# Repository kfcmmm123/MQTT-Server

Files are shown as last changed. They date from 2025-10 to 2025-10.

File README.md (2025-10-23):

# ESP32-POE-ISO IoT Control System
**Modular MQTT-Based Automation for Pumps, Ultrasonic Drivers, and Heaters**

This repository hosts a **multi-device IoT control platform** built on **ESP32-POE-ISO** boards communicating via **MQTT over Ethernet**.  
Each ESP32 node acts as a standalone controller for a subsystem (Pump, Ultrasonic, or Heater), while a Python controller (`iot_mqtt.py`) provides orchestration, supervision, and visualization.

---

## Project Overview

| Component | Description |
|---|---|
| **ESP32-POE-ISO Nodes** | Independent nodes for each subsystem. Each node runs its own safety-supervised firmware. |
| **Python Controller** | Publishes heartbeat and commands; logs telemetry from all devices. |
| **Mosquitto Broker** | Central MQTT message hub managing device topics and access control. |
| **CAD Models** | Modular enclosures for each ESP node and relay system. |

Each subsystem connects through a unified topic schema and supports **autonomous safety shutdown**, **timed operation**, and **real-time telemetry**.

---

## Features

- **Modular MQTT Architecture:** each node operates independently but shares a common protocol.
- **Ethernet + PoE Isolation:** hardware-level safety and simplified wiring.
- **PID Temperature Control:** with ADS1015 ADC + NTC thermistors for precise heater regulation.
- **Relay Control (I²C/Qwiic):** reliable actuation of pumps, heaters, and ultrasonic drivers.
- **Safety Supervision:** heartbeat monitoring, link detection, MQTT reconnection handling, and auto-failsafe.
- **Cross-Platform Python API:** unified control, MQTT utilities, and broker automation.

---

## Repository Structure

```
MQTT-Server/
│
├── README.md                     # Project overview & quickstart
│
├── devices/                      # ESP32 firmware & documentation
│   ├── pump/                        # Pump control firmware
│   │   ├── Pump_quad_client.ino     # Quad relay pump controller
│   │   ├── Pump_single_client.ino   # Single relay pump controller  
│   │   ├── Pump_Safety_client.ino   # Safety-enabled version for single relay
│   │   └── README.md                # Pump setup guide
│   │
│   ├── ultrasonic/                  # Ultrasonic driver control
│   │   ├── Ultrasonic_quad_client.ino          # Quad relay ultrasonic controller
│   │   ├── Ultrasonic_single_client.ino        # Single relay ultrasonic controller
│   │   ├── Ultrasonic_Safety_client.ino        # Safety-enabled version for single relay
│   │   └── README.md                # Ultrasonic setup guide
│   │
│   └── heater/                      # Heater control with PID
│       ├── Heater_client.ino        # Main heater firmware
│       ├── Heater_Safety_client.ino # Safety-enabled version
│       └── README.md                # Heater setup guide
│
├── iot_mqtt/                     # Python control library
│   ├── iot_mqtt.py                  # Unified MQTT API
│   ├── MQTT_Demo.ipynb              # Example Jupyter notebook
│   └── README.md                    # Python API documentation
│
├── mosquitto_config/             # MQTT broker configuration
│   ├── mosquitto.conf               # Broker settings
│   ├── aclfile.txt                  # Access control list
│   └── README.md                    # Broker setup guide
│
└── hardware/                     # 3D printable enclosures
    ├── CAD_models/                  # 3MF files for printing
    └── README.md                    # Hardware assembly guide
```

---

## System Architecture

```text
                 ┌─────────────────────────────┐
                 │         MQTT Broker         │
                 │        (Mosquitto)          │
                 │       Port 1883 (TCP)       │
                 └──────────────┬──────────────┘
                                │
                         Ethernet TCP/IP
          ┌─────────────────────┼────────────────────┐
          │                     │                    │                    
┌─────────┴──────────┐  ┌───────┴────────┐   ┌───────┴─────────┐
│ ESP32-POE-ISO      │  │ ESP32-POE-ISO  │   │ ESP32-POE-ISO   │
│ Node: pumps/01     │  │ Node: ultra/01 │   │ Node: heat/01   │
│ Relays (pumps)     │  │ Relays (ultra) │   │ SSR + ADS1015   │
└────────────────────┘  └────────────────┘   └─────────────────┘

````

---

## Device Overview

| Node | Features | Firmware |
| --- | --- | --- |
| **Pump Node** | Controls up to 4 DC peristaltic pumps via Qwiic relay | `devices/pump/Pump_Safety_client.ino`|
| **Ultrasonic Node** | Controls 2 ultrasonic driver boards via Qwiic relay | `devices/ultrasonic/Ultrasonic_Safety_client.ino` |
| **Heater Node** | Controls 2 heaters via Qwiic SSR + thermistor sensing + PID + safety brake | `devices/heater/Heater_Safety_client.ino` |

Each firmware implements MQTT topic handlers, safety gating, and local timers for timed activation (`ON:<ms>`).

---

## Software Stack

| Layer | Technology |
| --- | --- |
| **Hardware** | ESP32-POE-ISO (Olimex) |
| **Firmware** | Arduino framework |
| **Communication** | MQTT (paho-mqtt / PubSubClient) |
| **Broker** | Mosquitto |
| **Python API** | `iot_mqtt.py` |
| **Safety** | Heartbeat + LWT watchdogs |

---

## Security and Safety Summary

* **MQTT ACLs:** device-level topic restrictions in `mosquitto_config/aclfile.txt`
* **LWT Fail-safe:** controller disconnect triggers `OFFLINE` → all nodes shut down
* **Timeouts:** configurable per-device heartbeat timeouts
* **Hardware:** PoE isolation + fused 12 V supply + SSR isolation
* **Emergency Stop:** physical NC E-stop in series with actuator supply

---

## Quick Start

### Prerequisites
- ESP32-POE-ISO boards (Olimex)
- SparkFun Qwiic relay modules
- Python 3.8+ with `paho-mqtt` library
- Arduino IDE with ESP32 support

### 1. Setup MQTT Broker
```bash
# Install Mosquitto (Windows)
choco install mosquitto

# Or Linux
sudo apt install mosquitto mosquitto-clients

# Configure broker (see mosquitto_config/README.md)
mosquitto -v -c mosquitto_config/mosquitto.conf
```

### 2. Flash ESP32 Devices
1. Open Arduino IDE
2. Install ESP32 board support
3. Flash firmware from `devices/` folders:
    - **Pump Node**: `devices/pump/Pump_Safety_client.ino`
    - **Ultrasonic Node**: `devices/ultrasonic/Ultrasonic_Safety_client.ino`
    - **Heater Node**: `devices/heater/Heater_Safety_client.ino` 

### 3. Run Python Controller
```bash
# Install dependencies
pip install paho-mqtt

# Run example
python iot_mqtt/iot_mqtt.py
```

### 4. Monitor System
```bash
# Watch all MQTT traffic
mosquitto_sub -v -t "#" -u pyctl-controller -P controller
```

### 5. Test Devices
```python
import time
from iot_mqtt import PumpMQTT, UltraMQTT, HeatMQTT

# Control pumps
pumps = PumpMQTT(broker="192.168.0.100", username="pump1", password="pump")
pumps.ensure_connected()
pumps.on(1, 2000)  # Pump 1 for 2 seconds

# Control ultrasonic drivers
ultra = UltraMQTT(broker="192.168.0.100", username="ultra1", password="ultra")
ultra.ensure_connected()
ultra.on(1, 2000)  # Ultrasonic 1 for 2 seconds

# Control heaters with PID
heat = HeatMQTT(broker="192.168.0.100", username="heat1", password="heat")
heat.ensure_connected()
heat.set_target(1, 42.0)  # Set 42°C target
heat.pid_on(1)            # Enable PID control
time.sleep(2)             # On for 2 seconds
heat.set_target(1, 42.0)  # Set 42°C target
heat.pid_on(1)            # Enable PID control
```

---

## Documentation & Guides

### Setup & Configuration
- **[MQTT Broker Setup](./mosquitto_config/README.md)** - Mosquitto installation, users, ACL configuration
- **[Python API Guide](./iot_mqtt/README.md)** - Complete Python library documentation with examples
- **[Hardware Assembly](./hardware/README.md)** - 3D printable enclosures and assembly instructions

### Device-Specific Guides  
- **[Pump Controllers](./devices/pump/README.md)** - 4-pump relay control setup and wiring
- **[Ultrasonic Controllers](./devices/ultrasonic/README.md)** - AC driver control via relays
- **[Heater Controllers](./devices/heater/README.md)** - Dual SSR + PID temperature control

### Development Resources
- **[Jupyter Demo](./iot_mqtt/MQTT_Demo.ipynb)** - Interactive examples and testing
- **[CAD Models](./hardware/CAD_models/)** - 3MF files for 3D printing enclosures
- **[BOM](./hardware/BOM/)** - Bill of Materials for the setup

---

## Troubleshooting

### Common Issues

**ESP32 won't connect to MQTT**
- Check broker IP address in firmware (use `ipconfig` to verify network settings)
- Verify Ethernet connection and PoE power supply
- Confirm MQTT credentials match ACL configuration

**Broker stops responding with continuous client reconnections**
> **IMPORTANT**: This indicates a critical broker failure!
- Stop the broker immediately and wait until `netstat -ano | findstr :1883` shows no output
- Restart Jupyter/kernel to clear client connections
- **Root cause**: Server failure causes clients to reconnect with same client IDs, creating connection conflicts that overwhelm the broker

**Broker startup fails**
- Check for existing broker process: `netstat -ano | findstr :1883`
- If process exists, kill it: `taskkill /IM mosquitto.exe /F`
- Verify broker configuration: `ipconfig`, and port availability (default 1883)

**Devices show OFFLINE**
- Verify controller beacon is running (`pyctl/heartbeat` topic)
- Check heartbeat intervals (default 15s)
- Ensure LWT (Last Will & Testament) is properly configured

**Python API connection fails**
- Install required dependencies: `pip install paho-mqtt`
- Check broker address and port (default 1883)
- Verify user credentials match broker configuration (also check for user access rights in ACL file)
- **Check Python controller log file** - The `iot_mqtt.py` has built-in logging that writes detailed connection and communication logs to a log file

**Python controller issues**
- Check the log file created by `iot_mqtt.py` for detailed error messages and connection status
- Log file contains MQTT connection attempts, device status updates, and communication errors
- Look for authentication failures, connection timeouts, or topic permission errors in the logs

### Getting Help

**Debug MQTT Communication**
```bash
# Monitor all MQTT traffic
mosquitto_sub -v -t "#" -u pyctl-controller -P controller

# Check specific device topics
mosquitto_sub -v -t "pumps/01/#" -u pump1 -P pump
mosquitto_sub -v -t "heat/01/#" -u heat1 -P heat
```

**Additional Resources**
- **Check Python controller log file** - Built-in logging provides detailed connection status, MQTT communication, and error messages
- Check device-specific README files for detailed troubleshooting
- Review broker logs for authentication and connection issues
- Verify network connectivity with `ping <broker-ip>`
- Test broker connectivity: `mosquitto_pub -h <broker-ip> -t "test" -m "hello"`

---

## License

**MIT License**

© 2025 Alan Yang — Acceleration Consortium, University of Toronto

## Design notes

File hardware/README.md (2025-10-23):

# Hardware Assembly — Modular Tower System

This folder contains the **3D-printable designs** and assembly instructions for the modular tower system, including the Power Tower base unit, interchangeable module plates, and accessories for the IoT control system.

## Quick Links

- **[Python API Documentation](../iot_mqtt/README.md)** - Control ESP32 devices via Python
- **[Device Firmware](../devices/)** - ESP32 firmware for pumps, heaters, ultrasonic controllers
- **[MQTT Broker Setup](../mosquitto_config/README.md)** - Mosquitto configuration and security

---

## CAD Files

```
hardware/
├── CAD_models/                 # 3D printable enclosure files
│   ├── Base Power Tower.3mf
│   ├── Heater Module - SSR.3mf
│   ├── Pump Module - 3 single relay.3mf
│   ├── Pump Module - quad relay.3mf
│   ├── Ultrasonic Driver Module.3mf
│   └── Ultrasonic Module - 2 single relay.3mf
│
├── BOM/                        # Bill of Materials 
│   └── Modular MQTT Tower.xlsx 
│
├── Images/                     # Images of the setup
│   ├── Modular_Tower_Front.jpg 
│   ├── Modular_Tower_Side.jpg 
│   └── Power_Tower.jpg 
│
└── README.md                   # This assembly guide
```

---

## System Overview

The hardware system uses a **modular tower architecture** with a central power unit and interchangeable modules:

### Power Tower (Base Unit)
- **Wall Connection**: 120VAC power inlet from wall socket with fuse + switch
- **Built-in Components**: 
  - **Contactor**: Main power switching and control
  - **Emergency Stop (E-Stop)**: Safety circuit for immediate power cutoff
  - **Power Supply**: 120VAC to 12VDC conversion
  - **Filtering**: Capacitors (1000 µF + 0.1 µF) and TVS diode for clean power

### Modular Tower System
The tower supports multiple **interchangeable modules** that stack on top of the power tower:

#### Pump Module (2-Plate Design)
- **Plate 1**: 3 pump slots for DC peristaltic pumps
- **Plate 2**: 12VDC power input + ESP32 + Qwiic relays + capacitors (1000 µF + 0.1 µF) + TVS diode
- **Power**: 12VDC distributed from main power tower
- **Control**: 3-channel pump control via Qwiic relays

#### Ultrasonic Module (3-Plate Design)
- **Plate 1**: 1 ultrasonic driver board (120W)
- **Plate 2**: 1 ultrasonic driver board (120W) 
- **Plate 3**: 120VAC power input + ESP32 + Qwiic relays
- **Power**: 120VAC distributed from main power tower
- **Control**: 2-channel ultrasonic driver control

#### Heater Module (1-Plate Design)
- **Plate 1**: ESP32 + Dual SSR + ADS1015 ADC + LCD display + 120VAC input
- **Power**: 120VAC distributed from main power tower
- **Control**: 2-channel SSR control using PID temperature control with thermistor sensing

### System Images

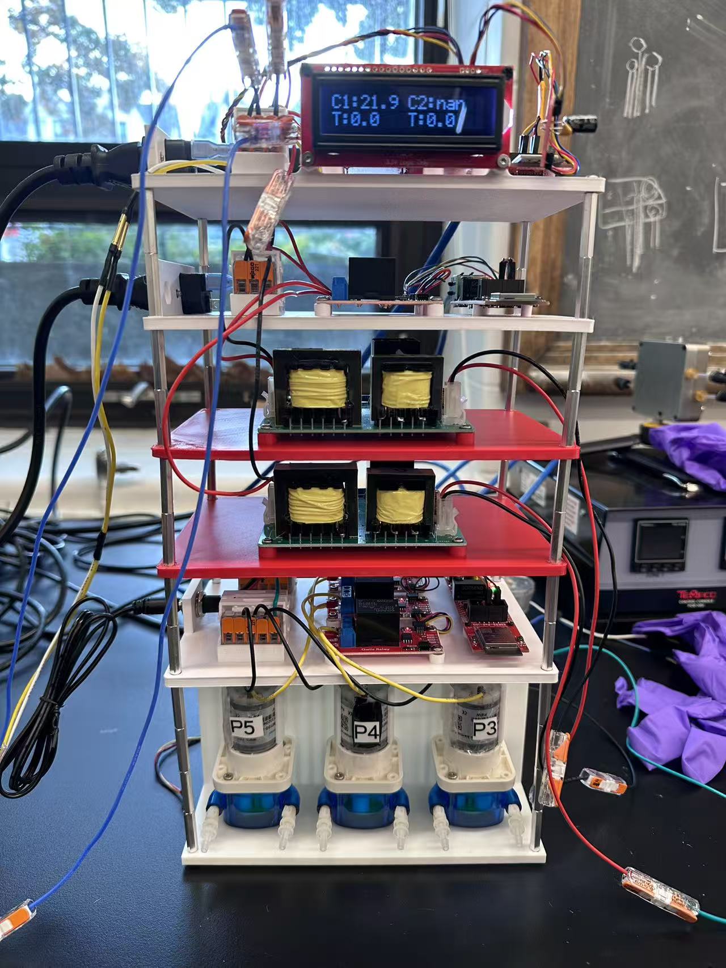
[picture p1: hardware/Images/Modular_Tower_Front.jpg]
Modular Tower Front View

*Complete modular tower system - front view showing all modules stacked*

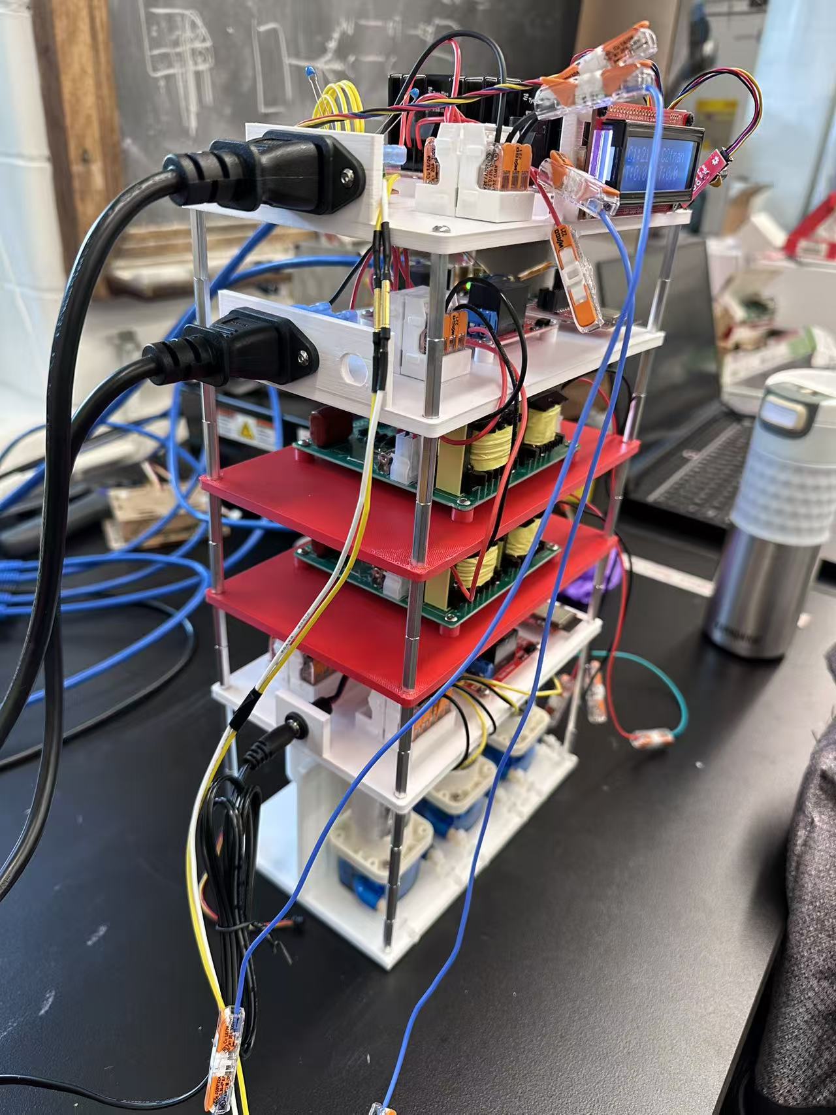
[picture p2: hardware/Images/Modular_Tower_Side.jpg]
Modular Tower Side View

*Side view showing the modular stacking and cable management*

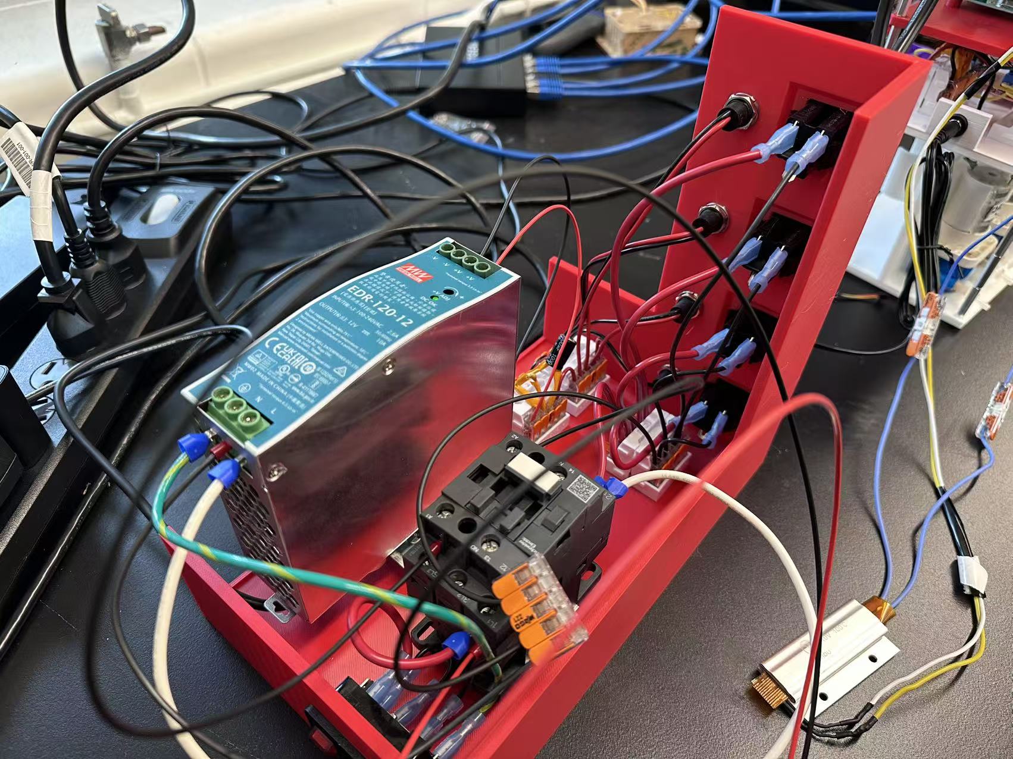
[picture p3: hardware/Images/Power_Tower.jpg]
Power Tower Base

*Power Tower base unit with contactor, E-Stop, and power distribution*

---

## Assembly Process

### 1. Power Tower Assembly
1. Print the **Base Power Tower** enclosure
2. Add M6 heat inserts and secure the DIN rail (35.00mm x 7.50mm), M3 inserts for WAGO connector carriers, and power inlet + outlets
3. Install the **contactor, E-Stop, power supply, and filtering components** on DIN rail
4. Wire the **120VAC inlet** (16AWG) and **power distribution** to module connectors
5. Install **filtering capacitors** (1000 µF + 0.1 µF) and **TVS diode** for clean power
6. Test power distribution and safety circuits

### 2. Module Assembly
1. **Print module plates** for your specific configuration (pump, ultrasonic, heater)
2. Add appropriate heat inserts (M3, M2, M6) and secure WAGO connector carriers and power inlet
3. **Install electronics** on each plate:
   - **ESP32**: Mount with M2 screws 
   - **Relays/SSR**: Mount with M3 screws, maintain 5-7mm spacing for heat ventilation
   - **Filtering**: Install capacitors (1000 µF + 0.1 µF) and TVS diodes
4. **Wire power and communication** connections (16AWG for VAC, 20AWG for VDC)
5. **Test individual modules** before stacking

### 3. Tower Stacking
1. **Stack modules** on top of the Power Tower base using M3 standoffs (25 mm)
2. **Connect power and communication** between modules
3. **Install cable management** and strain relief
4. **Final testing** of complete system

---

## Hardware Components

### Power Tower Components
- **Contactor**: Main power switching (rated for your load requirements)
- **Emergency Stop**: NC contactor in series with actuator supply
- **Power Supply**: 120VAC to 12VDC conversion (rated for total module load)
- **Filtering**: Capacitors (1000 µF + 0.1 µF) and TVS diode for clean power
- **DIN Rail**: Standard 35.00mm x 7.50mm DIN rail for contactor and power supply mounting
- **WAGO Connectors**: Spring-loaded connectors for reliable connections

### Module Components
- **Olimex ESP32-POE-ISO**: Main controller with Ethernet and PoE
- **Qwiic Relays**: SparkFun relay modules for switching
- **Dual SSR**: Solid state relays for heater control
- **ADS1015**: ADC for temperature sensing
- **LCD Display**: 16x2 I²C display for status monitoring
- **Filtering Components**: Capacitors (1000 µF + 0.1 µF) and TVS diodes for each module

### Fasteners & Hardware

#### Standoffs & Spacing
- **M3 Standoffs**: 25mm standoffs for module stacking
- **Component Spacing**: 5-7mm between Qwiic relays and SSRs for heat ventilation

#### Heat-set Inserts
- **M3 × 4mm**: Standard board mounting
- **M6 × 4mm**: DIN rail mounting  
- **M2 × 3mm**: ESP32 board mounting

#### Screws & Fasteners
- **M6 screws**: DIN rail mounting
- **M3 screws**: All components except ESP32
- **M2 screws**: ESP32 board mounting only

#### Cable Specifications
- **16AWG**: 120VAC power connections
- **20AWG**: 12VDC power and signal connections
- **Ethernet**: Cat5e or Cat6 for network connections

---

## Power Ratings & Specifications

### Power Tower
- **Input**: 120VAC, 15A maximum (with appropriate fuse)
- **Output**: 12VDC, 10A maximum (adjust based on total module load)

### Module Power Requirements
- **Pump Module**: 12VDC, ~2A per pump (6A total for 3 pumps)
- **Ultrasonic Module**: 120VAC, ~1A per driver (2A total for 2 drivers)
- **Heater Module**: 120VAC, ~8A per heater (16A total for 2 heaters)

### Safety Ratings
- **TVS Diodes**: Appropriate voltage ratings for protection
- **Capacitors**: 1000 µF electrolytic + 0.1 µF ceramic for filtering
- **Cable Ratings**: 16AWG for 120VAC, 20AWG for 12VDC

---

## Print Settings (Reference)

- **Material:** PETG (preferred for heat & chemicals); PLA+ acceptable for dry bench use.
- **Nozzle/Layer:** 0.4 mm nozzle; 0.2 mm layer height.
- **Walls:** 3 perimeters; top/bottom 4–5 layers.
- **Infill:** 20–30% grid/gyroid.
- **Supports:** Only for board standoffs that overhang >50° (most parts are support-free).
- **Tolerances:** All snap/groove fits modeled at +0.3 mm clearance for PETG.

---

## Safety Notes

- Maintain **creepage/clearance** for mains relay sections (≥6 mm).  
- Use **printed guards** around AC terminals; never expose live screws.  
- Prefer **PETG/ABS** near warm SSRs or heaters; avoid PLA if ambient > 40 °C.  
- Label **inlets/outlets** and emergency-stop clearly (DXF included).

---

## Revision Log

- `v1.0` – Initial enclosure set and rail concept.  
- `v1.1` – Added LCD window and stronger lid ribs.  
- `v1.2` – Cable gland spacing increased, thermistor clamp added.

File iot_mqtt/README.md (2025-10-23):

# Python MQTT API — ESP32-POE-ISO Device Control

This document explains how to use the **Python MQTT API (`iot_mqtt.py`)** to control ESP32-POE-ISO device nodes (pumps, heaters, ultrasonic drivers) via MQTT communication.

## Quick Links

- **[Broker Setup](../mosquitto_config/README.md)** - Mosquitto installation and configuration
- **[Device Firmware](../devices/)** - ESP32 firmware for pumps, heaters, and ultrasonic controllers
- **[Hardware Assembly](../hardware/README.md)** - 3D printable enclosures and assembly

---

## 1. Overview

The MQTT network consists of:
- **Broker:** Mosquitto server (usually on your PC or Raspberry Pi)
- **Controller:** Python beacon (publishes heartbeat + commands)
- **ESP32 Nodes:** individual clients (pumps, ultrasonic, heater)

Each device uses authentication and a dedicated topic subtree for clean separation.

## 2. Installation

```bash
# Install Python dependencies
pip install paho-mqtt>=1.6.0

# Or use requirements.txt
pip install -r requirements.txt
```

---

## 3. Broker Setup (Mosquitto)

> **Note**: For detailed broker setup instructions, see [Mosquitto Configuration Guide](../mosquitto_config/README.md).

### Installation
**Windows**
```bash
choco install mosquitto
````

**Linux**

```bash
sudo apt install mosquitto mosquitto-clients
sudo systemctl enable mosquitto
```

### Configuration

Edit `mosquitto_config/mosquitto.conf`:

```conf
listener 1883
allow_anonymous false
password_file "C:/Program Files/mosquitto/passwd"
acl_file      "C:/Program Files/mosquitto/aclfile.txt"
persistence true
persistence_location "C:/Program Files/mosquitto/data/"
```

### Create Users

```bash
mosquitto_passwd -c passwd pyctl-controller
mosquitto_passwd    passwd pump1
mosquitto_passwd    passwd ultra1
mosquitto_passwd    passwd heat1
```

### Launch Broker

```bash
mosquitto -v -c "C:/Program Files/mosquitto/mosquitto.conf"
```

---

## 3. Access Control

Example ACL (`mosquitto_config/aclfile.txt`):

```text
# Controller
user pyctl-controller
topic write pyctl/#
topic read  pumps/01/#
topic read  ultra/01/#
topic read  heat/01/#

# Pump
user pump1
topic read pyctl/#
topic write pumps/01/#

# Ultrasonic
user ultra1
topic read pyctl/#
topic write ultra/01/#

# Heater
user heat1
topic read pyctl/#
topic write heat/01/#
```

---

## 4. Python MQTT Library (`iot_mqtt.py`)

### Quick Example

```python
# iot_mqtt_demo.py
import time
from iot_mqtt import start_broker_if_needed, stop_broker
from iot_mqtt import PumpMQTT, UltraMQTT, HeatMQTT

# Optional: start a local Mosquitto on Windows if not already running
proc = start_broker_if_needed()  # comment if your broker is already running

# Start controller beacon
beacon = ControllerBeacon(
    broker=broker,
    username="pyctl-controller", password="controller",
    status_topic="pyctl/status", heartbeat_topic="pyctl/heartbeat",
    heartbeat_interval=5.0, keepalive=30,
)
beacon.start()

# Create clients (replace IP with your broker's LAN IP)
pumps = PumpMQTT(broker="192.168.0.101", username="pico1",  password="pump",
                 base_topic="pumps/01", client_id="pyctl-pumps")
ultra = UltraMQTT(broker="192.168.0.101", username="ultra1", password="ultra",
                  base_topic="ultra/01", client_id="pyctl-ultra")
heat  = HeatMQTT(broker="192.168.0.101", username="heat1",  password="heat",
                 base_topic="heat/01",  client_id="pyctl-heat")

# Connect + start background loops
pumps.ensure_connected(); ultra.ensure_connected(); heat.ensure_connected()
time.sleep(1)  # let subscriptions settle

# Quick status snapshots (retained + live)
pumps.status(seconds=2.0)
ultra.status(seconds=2.0)
heat.status(seconds=2.0)

# ---- Control examples ----
# Pumps
pumps.on(1); time.sleep(1)
pumps.on(1, 2000)            # auto-off after 2s
time.sleep(2.5)

# Ultrasonic
ultra.on_for(2, 1500)        # ch2 for 1.5s
time.sleep(2)

# Heaters (PID demo)
heat.set_base_temp(1, 42.0)  # retained at heat/01/target/1
heat.pid_on(1)

# Read temp for ~30s
for _ in range(30):
    try:
        t = heat.get_base_temp(1, timeout_s=2.0)
        print("Heater1 Temp =", t)
    except TimeoutError:
        print("Temp read timeout")
    time.sleep(1)

# Stop PID and ensure OFF
heat.pid_off(1)
heat.set_pwm(1, 0)
heat.off(1)

# Cleanup
pumps.disconnect(); ultra.disconnect(); heat.disconnect()
stop_broker(proc)
```

### Command Payloads

| Category | Command | Example Payload | Description |
| --- | --- | --- | --- |
| **General** | `ON`, `OFF`, `ON:<ms>` | `ON:2000` | Turn relay ON for given ms (auto-off) |
| **Heater**  | `PWM:<0–100>` | `PWM:50` | Apply PWM % output |
| | `SET:<temp>` | `SET:42.0` | Set PID target |
| | `PID:ON` / `PID:OFF` | — | Enable/disable PID loop |
| | `GET` | — | Request temperature publish |

---

## 5. Topic Map Summary

| Topic | Direction | Description |
| --- | --- | --- |
| `<base>/cmd/<n>` | Controller → ESP | Command for channel n |
| `<base>/state/<n>`  | ESP → Controller | Actuator state |
| `<base>/temp/<n>` | ESP → Controller | Temperature (heater) |
| `<base>/target/<n>` | ESP → Controller | PID target |
| `<base>/status` | ESP ↔ Controller | ONLINE/OFFLINE (retained) |
| `<base>/heartbeat`  | ESP ↔ Controller | “1” periodically |
| `pyctl/status` | Controller ↔ ESP | Controller ONLINE/OFFLINE |
| `pyctl/heartbeat` | Controller ↔ ESP | Controller heartbeat |

---

## 6. Safety Behavior

| Condition | Action |
| --- | --- |
| No controller heartbeat | All outputs OFF |
| MQTT disconnected | All outputs OFF |
| Ethernet down | All outputs OFF |
| Controller crash | LWT sets `pyctl/status = OFFLINE` → all nodes OFF |
| ON command no duration  | Auto OFF after lease (`MAX_ON_LEASE_MS`) |

---

## 7. Troubleshooting

* **Broker rejects connection:** recheck user/pass and ACL.
* **No telemetry:** verify ESP node IP and Ethernet link.
* **Device doesn’t turn OFF after PC crash:** check LWT enabled and controller beacon running.
* **“CTRL timeout” warnings:** ensure first heartbeat received before timeout starts.

---

## 8. References

* [Mosquitto Docs](https://mosquitto.org/documentation/)
* [Paho MQTT Python Client](https://pypi.org/project/paho-mqtt/)
* [ESP32 Arduino PubSubClient](https://github.com/knolleary/pubsubclient)

---

## 🪪 License

MIT © 2025 Alan Yang

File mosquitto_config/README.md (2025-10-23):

# Mosquitto Broker — Configuration & Security

This folder contains the **Mosquitto MQTT broker configuration** and **access control lists** for the ESP32-POE-ISO IoT control system.

## Configuration Files

- **`mosquitto.conf`** – Main broker configuration (listener, persistence, authentication)
- **`aclfile.txt`** – Topic-level permissions and access control per user

## Quick Links

- **[Python API Documentation](../iot_mqtt/README.md)** - Control ESP32 devices via Python
- **[Device Firmware](../devices/)** - ESP32 firmware for pumps, heaters, ultrasonic controllers
- **[Hardware Assembly](../hardware/README.md)** - 3D printable enclosures and assembly

---

## 1) Install Mosquitto

**Windows**
- Download the official installer or use `choco install mosquitto`.
- Ensure the service has permission to read the config and data paths.

**Ubuntu/Debian**
```bash
sudo apt update
sudo apt install mosquitto mosquitto-clients
sudo systemctl enable mosquitto
````

---

## 2) Configuration File

Edit paths in `mosquitto.conf` to match your machine (Windows example shown):

```conf
listener 1883
allow_anonymous false

# Auth files (edit these paths!)
password_file "C:/Program Files/mosquitto/passwd"
acl_file      "C:/Program Files/mosquitto/aclfile.txt"

# Persistence (safe restarts, retained messages)
persistence true
persistence_location "C:/Program Files/mosquitto/data/"

# Optional: logging
log_timestamp true
log_type all
```

> On Linux, typical paths are `/etc/mosquitto/mosquitto.conf`,
> `/etc/mosquitto/passwd`, `/etc/mosquitto/aclfile.txt`, and `/var/lib/mosquitto/`.

---

## 3) Users & Passwords

Create users with `mosquitto_passwd`.
**Important:** `-c` creates/overwrites the file—use it *once*.

```bash
# First time only (creates the file)
mosquitto_passwd -c passwd pyctl-controller

# Add device users
mosquitto_passwd    passwd pump1
mosquitto_passwd    passwd ultra1
mosquitto_passwd    passwd heat1
```

Move `passwd` to the path referenced in `mosquitto.conf`.

---

## 4) ACL (Access Control)

`aclfile.txt` grants the minimum required permissions:

```text
# Controller (Python)
user pyctl-controller
topic write pyctl/#
topic read  pumps/01/#
topic read  ultra/01/#
topic read  heat/01/#

# Pump device
user pump1
topic read  pyctl/#
topic read  pumps/01/cmd/#
topic write pumps/01/state/#
topic write pumps/01/status
topic write pumps/01/heartbeat

# Ultrasonic device
user ultra1
topic read  pyctl/#
topic read  ultra/01/cmd/#
topic write ultra/01/state/#
topic write ultra/01/status
topic write ultra/01/heartbeat

# Heater device
user heat1
topic read  pyctl/#
topic read  heat/01/cmd/#
topic write heat/01/state/#
topic write heat/01/status
topic write heat/01/heartbeat
topic write heat/01/temp/#
topic write heat/01/target/#
```

> If you create more nodes (e.g., `pumps/02`), add matching blocks here.

---

## 5) Start the Broker

**Windows (console):**

```powershell
"C:\Program Files\mosquitto\mosquitto.exe" -v -c "C:\Program Files\mosquitto\mosquitto.conf"
```

**Linux (service):**

```bash
sudo systemctl restart mosquitto
sudo journalctl -u mosquitto -f
```

---

## 6) Smoke Test

Open two terminals:

```bash
# Terminal A – subscribe to everything (dev use only)
mosquitto_sub -h 127.0.0.1 -t "#" -v -u pyctl-controller -P controller

# Terminal B – publish a test message
mosquitto_pub -h 127.0.0.1 -t "pyctl/heartbeat" -m "1" -u pyctl-controller -P controller
```

You should see the message in Terminal A.

---

## 7) Optional: TLS (Encrypted MQTT)

1. Generate or obtain certificates (self-signed or from your CA).
2. Add to `mosquitto.conf`:

```conf
listener 8883
cafile     /etc/mosquitto/certs/ca.crt
certfile   /etc/mosquitto/certs/server.crt
keyfile    /etc/mosquitto/certs/server.key
require_certificate false
```

3. Point Python/ESP clients to port **8883** and provide CA certs.

---

## 8) Persistence & Backups

* **Retained messages** (e.g., `status`, `target/`) are saved to the persistence store.
* Back up the directory referenced by `persistence_location` regularly.
* To reset the broker state during development, stop Mosquitto and delete the persistence DB (⚠️ clears retained topics).

---

## 9) Troubleshooting

* **`Not authorized`** → user doesn’t match the ACL; verify username, topic base, and that you didn’t recreate the password file with `-c`.
* **No retained messages** → persistence disabled or the broker lacks write permission to the persistence directory.
* **Clients disconnecting** → increase `keepalive` (30–60 s) and check for duplicate client IDs.
* **Windows service can’t read files** → run as a user with access or move config to a user-writable path.

---

## 10) Security Hardening Checklist

* [x] `allow_anonymous false`
* [x] Unique users per device class
* [x] Minimal ACL permissions per subtree
* [x] Enable persistence and log to file
* [x] Optional TLS (port 8883) on shared or Wi-Fi networks
* [x] Use **LWT** in clients for failsafe OFF handling

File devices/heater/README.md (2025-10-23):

# Heater Controllers — ESP32-POE-ISO PID Temperature Control

## Overview

ESP32-POE-ISO nodes control heating elements via **SparkFun Qwiic Dual Solid State Relay** with **PID temperature control**. Temperature sensing uses **ADS1015 ADC** with **NTC thermistors**. Features include setpoint control, manual PWM, and comprehensive safety systems.

## Available Firmware

- **`Heater_client.ino`** - Main heater controller with PID temperature control using SparkFun SSR
- **`Heater_Safety_client.ino`** - Safety-enhanced version with watchdog supervision

> **Recommended**: Use `Heater_Safety_client.ino` for production deployments.

## Hardware

* **MCU**: Olimex **ESP32-POE-ISO**
* **SSR**: SparkFun **Qwiic Dual Solid State Relay** (I²C, default `0x0A`)
* **ADC**: **ADS1015** (I²C) for thermistors
* **Thermistors**: NTC 10 k, with divider resistor **RC = 10 kΩ** to **VCC = 3.3 V**
* **Power**: PoE/USB for ESP; heater power routed by SSR (match SSR ratings)

## Wiring

* ESP32 I²C → Dual SSR → heater loads
* ESP32 I²C → ADS1015
* Two thermistor dividers:

  * **VCC(3.3 V)** → fixed **RC=10 kΩ** → **node** → **NTC** → **GND**
  * ADS1015 **A0** reads node (heater 1), **A1** reads node (heater 2)
* Keep sensor wiring away from heater power where possible

## Constants (already in sketch)

```cpp
#define HEATER_MAX 100     // PID output upper limit (% PWM)
#define HEATER_MIN 0       // PID output lower limit
#define RC     10000.0     // Divider fixed resistor (Ω)
#define VCC    3.3         // Reference (V)
#define R25    10000.0     // Thermistor @25°C (Ω)
#define B2585  3977.0      // Beta constant (K)
```

## MQTT

**Base**: `heat/01`

| Topic | Dir  | Example Payload | Notes |
| --- | :----: | --- | --- |
| `heat/01/cmd/<n>` | PC→ESP | `ON` · `OFF` · `ON:2000` · `PWM:35` · `SET:42.0` · `PID:ON` · `PID:OFF` · `GET` | Channel `<n>` ∈ {1,2} |
| `heat/01/state/<n>`  | ESP→PC | `ON`/`OFF` *(retained)* | |
| `heat/01/target/<n>` | ESP→PC | `42.0` *(retained)* | PID setpoint |
| `heat/01/temp/<n>` | ESP→PC | `39.6` | Current temperature |
| `heat/01/status` | ESP→PC | `ONLINE`/`OFFLINE` *(retained)* | |
| `heat/01/heartbeat`  | ESP→PC | `1` every 15 s | |

**Commands (payloads to `heat/01/cmd/<n>`)**

* **Manual**: `ON`, `OFF`, `ON:<ms>`, `PWM:<0–100>`
* **PID**: `SET:<tempC>`, `PID:ON`, `PID:OFF`
* **Telemetry**: `GET` → immediately publishes `temp/<n>`

## PID & Safety (what the firmware does)

* PID: `AutoPID` using `Kp/Ki/Kd` (in code) drives **slow PWM** (0–100 %) to the SSR.
* Safety:

  * **Sensor validity**: if thermistor read is out-of-range / NaN, SSR is forced **OFF**.
  * **Rate-of-rise brake**: if ΔT/Δt exceeds a threshold (config in code), firmware briefly clamps PWM/OFF to prevent runaway.
    Tune this based on your thermal mass and heater wattage.

## Configure & Build

1. **Arduino IDE Setup**:
   - Install ESP32 board support package
   - Install required libraries: `PubSubClient`, `SparkFun_Qwiic_Relay`, `Adafruit_ADS1X15`, `AutoPID`, `Wire`

2. **Configuration**:
   - Set `MQTT_BROKER_IP` to your broker's IP address
   - Configure MQTT credentials (username/password)
   - Set base topic to `heat/01`
   - Map ADS channels (`TH_CH_1`, `TH_CH_2`) to your thermistor connections

3. **PID Tuning**:
   - Adjust `Kp/Ki/Kd` constants for your thermal system
   - Set rate-of-rise thresholds for safety brake
   - Configure sensor validity limits

4. **Upload**:
   - Select board: **ESP32 Dev Module**
   - Upload via USB to ESP32-POE-ISO

## Required Arduino Libraries

```cpp
#include <PubSubClient.h>           // MQTT communication
#include <SparkFun_Qwiic_Relay.h>   // SSR control
#include <Adafruit_ADS1X15.h>       // ADC for thermistors
#include <AutoPID.h>                // PID control algorithm
#include <Wire.h>                   // I²C communication
```

## Test (Python)

```python
import time
from iot_mqtt import HeatMQTT

# Connect to heater controller
heat = HeatMQTT(broker="192.168.0.100", username="heat1", password="heat", base_topic="heat/01")
heat.ensure_connected()

# Set target temperature and enable PID
heat.set_target(1, 42.0)      # Set 42°C target
heat.pid_on(1)                # Enable PID control

# Monitor temperature for 30 seconds
for _ in range(30):
    try:
        temp = heat.get_base_temp(1, timeout_s=2.0)
        print(f"Heater 1 Temperature: {temp}°C")
    except TimeoutError:
        print("Temperature read timeout")
    time.sleep(1)

# Stop heating
heat.pid_off(1)               # Disable PID
heat.set_pwm(1, 0)            # Set PWM to 0%
heat.off(1)                   # Ensure heater is off
heat.disconnect()
```

See [Python API Documentation](../iot_mqtt/README.md) for complete usage examples.

## Troubleshooting

### Temperature Control Issues
- **Temperature readings erratic**: Check thermistor constants (`R25`, `B2585`), wiring, and tune `Kp/Ki/Kd` parameters
- **Temperature overshoot**: Reduce `Kp` gain or increase derivative term `Kd` for better damping
- **Slow response**: Increase `Kp` gain or reduce integral time `Ki`

### Hardware Issues
- **No ADS1015 detected**: Check I²C address, pull-ups (Qwiic has them), and cable connections
- **Safety brake triggers immediately**: Loosen rate-of-rise limit or verify ADC wiring (floating input can appear as fast temperature change)
- **SSR not switching**: Check I²C communication to relay module and verify SSR power supply

### Safety Issues
- **Heater stays on after disconnect**: Check controller beacon is running (`pyctl/heartbeat` topic)
- **Random safety shutdowns**: Verify Ethernet connection stability and thermistor readings

See [Main Troubleshooting Guide](../../README.md#troubleshooting) for more details.

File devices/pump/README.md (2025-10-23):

# Pump Controllers — ESP32-POE-ISO MQTT Control

## Overview

ESP32-POE-ISO nodes control DC peristaltic pumps via **SparkFun Qwiic Relay** modules over I²C. Multiple firmware variants are available for different relay configurations. Each node exposes MQTT commands for **ON**, **OFF**, and **timed ON** operation with safety supervision.

## Available Firmware

- **`Pump_quad_client.ino`** - 4-pump controller using 1 SparkFun Qwiic Quad Relay
- **`Pump_single_client.ino`** - 3-pump controller using 3 SparkFun Qwiic Single Relay  
- **`Pump_Safety_client.ino`** - Safety-enhanced version with watchdog supervision (3 Single Relays)

> **Recommended**: Use `Pump_Safety_client.ino` for production deployments.

## Hardware

* **MCU**: Olimex **ESP32-POE-ISO**
* **Relay**: SparkFun **Qwiic Quad Relay** (I²C, default addr `0x6D`), or 3 **Qwiic Single Relay** (addr `0x18`, `0x19`, `0x09`)
* **Power**: PoE or 5 V via USB (PoE preferred)
* **Cabling**: Qwiic/JST-SH (I²C); pump power routed through relay contacts

## Wiring

* ESP32-POE-ISO I²C → Qwiic Relays (Qwiic cable)
* Pump positive lead → relay **COM**; relay **NO** → +12 V supply (or whatever your pump supply is)
* Pump negative lead → supply GND (common)
* Add per-pump flyback diode if the pump is inductive and relay is mechanical (across pump leads, band to +) e.g. 1N4007

## MQTT

**Base**: `pumps/01`

**Topics**

| Topic | Dir  | Example Payload | Notes |
| --- | :----: | --- | --- |
| `pumps/01/cmd/<n>` | PC→ESP | `ON` · `OFF` · `ON:1500` | Channel `<n>` ∈ {1..4} |
| `pumps/01/state/<n>` | ESP→PC | `ON` / `OFF` *(retained)* | Relay state |
| `pumps/01/status` | ESP→PC | `ONLINE` / `OFFLINE` *(retained)* | Node availability |
| `pumps/01/heartbeat` | ESP→PC | `1` every 15 s | Keep-alive |

**Commands (payloads to `pumps/01/cmd/<n>`)**

* `ON` — turn pump <n> on
* `OFF` — turn pump <n> off
* `ON:<ms>` — on for `<ms>` ms, then auto-off

## Configure & Build

1. **Arduino IDE Setup**:
   - Install ESP32 board support package
   - Install required libraries: `PubSubClient`, `SparkFun_Qwiic_Relay`, `Wire`

2. **Configuration**:
   - Set `MQTT_BROKER_IP` to your broker's IP address
   - Configure MQTT credentials (username/password)
   - Set base topic to `pumps/01` (or customize)

3. **Upload**:
   - Select board: **ESP32 Dev Module**
   - Upload via USB to ESP32-POE-ISO

## Required Arduino Libraries

```cpp
#include <PubSubClient.h>           // MQTT communication
#include <SparkFun_Qwiic_Relay.h>   // Relay control
#include <Wire.h>                   // I²C communication
```

## Test (Python)

```python
from iot_mqtt import PumpMQTT

# Connect to pump controller
pumps = PumpMQTT(broker="192.168.0.100", username="pump1", password="pump", base_topic="pumps/01")
pumps.ensure_connected()

# Test operations
pumps.on(1, 2000)      # Pump 1 for 2 seconds
pumps.status(2.0)      # Get status for 2 seconds
pumps.off(1)           # Ensure pump 1 is off
pumps.disconnect()
```

See [Python API Documentation](../iot_mqtt/README.md) for complete usage examples.

## Troubleshooting

### Connection Issues
- **No `ONLINE` status**: Check PoE link, USB power, and broker IP address
- **MQTT connection fails**: Verify broker is running and credentials match ACL configuration

### Hardware Issues  
- **I²C not found**: Run I²C scanner; ensure Qwiic cable is properly seated; default address is `0x6D`
- **Pump doesn't run**: Confirm external power supply, correct wiring to NO/COM contacts
- **Relay clicking but no pump**: Check flyback diodes for inductive loads

### Safety Issues
- **Pump stays on after timeout**: Check controller beacon is running (`pyctl/heartbeat` topic)

See [Main Troubleshooting Guide](../../README.md#troubleshooting) for more details.

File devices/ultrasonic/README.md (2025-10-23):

# Ultrasonic Controllers — ESP32-POE-ISO Driver Control

## Overview

ESP32-POE-ISO nodes control ultrasonic cleaning drivers via **SparkFun Qwiic Relay** modules. Multiple firmware variants support different relay configurations for AC or DC driver control. MQTT provides **ON**, **OFF**, and **timed ON** operation with safety supervision.

## Available Firmware

- **`Ultrasonic_quad_client.ino`** - 2-channel controller using 1 SparkFun Qwiic Quad Relay
- **`Ultrasonic_single_client.ino`** - 2-channel controller using 2 SparkFun Qwiic Single Relays
- **`Ultrasonic_Safety_client.ino`** - Safety-enhanced version with watchdog supervision (2 Single Relays)

> **Recommended**: Use `Ultrasonic_Safety_client.ino` for production deployments.

## Hardware

* **MCU**: Olimex **ESP32-POE-ISO**
* **Relay**: Qwiic Quad Relay (use 2 channels), or two single relays
* **Loads**: Two ultrasonic **driver boards** (your “13913887466 120 W” boards), powered from AC (through SSR) or DC (through relay), per your wiring plan
* **Power**: PoE/USB for ESP, appropriate mains/DC for the drivers (with proper fusing)

## Wiring

* ESP32 I²C → Qwiic Relay
* Each ultrasonic driver input power (or enable line) routed through its relay
* If switching **mains**, prefer **SSR** and keep creepage/clearance; fuse appropriately

## MQTT

**Base**: `ultra/01`

| Topic | Dir  | Example Payload | Notes |
| --- | :----: | --- | --- |
| `ultra/01/cmd/<n>` | PC→ESP | `ON` · `OFF` · `ON:1000` | Channel `<n>` ∈ {1,2} |
| `ultra/01/state/<n>` | ESP→PC | `ON`/`OFF` *(retained)* | |
| `ultra/01/status` | ESP→PC | `ONLINE`/`OFFLINE` *(retained)* | |
| `ultra/01/heartbeat` | ESP→PC | `1` every 15 s | |

**Commands**

* `ON`, `OFF`, `ON:<ms>` (same semantics as pumps)

## Configure & Build

1. **Arduino IDE Setup**:
   - Install ESP32 board support package
   - Install required libraries: `PubSubClient`, `SparkFun_Qwiic_Relay`, `Wire`

2. **Configuration**:
   - Set `MQTT_BROKER_IP` to your broker's IP address
   - Configure MQTT credentials (username/password)
   - Set base topic to `ultra/01`
   - Configure relay I²C addresses for your setup

3. **Upload**:
   - Select board: **ESP32 Dev Module**
   - Upload via USB to ESP32-POE-ISO

## Required Arduino Libraries

```cpp
#include <PubSubClient.h>           // MQTT communication
#include <SparkFun_Qwiic_Relay.h>   // Relay control
#include <Wire.h>                   // I²C communication
```

## Test (Python)

```python
import time
from iot_mqtt import UltraMQTT

# Connect to ultrasonic controller
ultra = UltraMQTT(broker="192.168.0.100", username="ultra1", password="ultra", base_topic="ultra/01")
ultra.ensure_connected()

# Test operations
ultra.on(1, 1500)        # Channel 1 for 1.5 seconds
ultra.status(2.0)        # Get status for 2 seconds
ultra.off(1)             # Ensure channel 1 is off
ultra.disconnect()
```

See [Python API Documentation](../iot_mqtt/README.md) for complete usage examples.

## Troubleshooting

### Connection Issues
- **No `ONLINE` status**: Check PoE link, USB power, and broker IP address
- **MQTT connection fails**: Verify broker is running and credentials match ACL configuration

### Hardware Issues
- **Both channels toggle together**: Verify correct relay channel addressing in code and wiring
- **Relay not switching**: Check I²C communication and relay power supply
- **Driver not responding**: Verify driver power supply and relay contact wiring

### Safety Issues
- **Driver stays on after timeout**: Check controller beacon is running (`pyctl/heartbeat` topic)
- **Random shutdowns**: Verify Ethernet connection stability and PoE power supply

### Mains Power Safety
- **AC driver control**: Use SSR and proper snubbers/fusing for mains switching
- **Wiring safety**: Keep low-voltage control and mains power wiring properly segregated
- **Isolation**: Ensure proper creepage/clearance distances for mains connections

See [Main Troubleshooting Guide](../../README.md#troubleshooting) for more details.

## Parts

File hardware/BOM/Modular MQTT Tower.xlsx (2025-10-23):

Country of Origin may be different at time of shipment.
The HTSUS and ECCN information shown is for informational purposes only and is not a representation or warranty as to the accuracy or reliability of these classifications. All information is provided "as is" and is subject to change without notice. Any use made of the information provided is without recourse to Digi-Key and at the user's risk.
Index | Manufacturer Part Number | Manufacturer Name | Description | Lead Time | Availability | Stock Status | Attrition % | Requested Quantity 1 | Pack Quantity 1 | Pack Type 1 | Digi-Key Part Number 1 | Unit Price 1 | Extended Price 1 | Minimum Order Quantity 1 | Customer Reference | Requested Part Number | Lead Weeks | Datasheet | Reference Designator | US Import Tariff | Note | Part Status | RoHS Status | Moisture Sensitivity Level (MSL) | ECCN | HTSUS | Country of Origin | Environmental Information | Original Part numbers | Image | Product Notes
1 | 1N4007 | Diotec Semiconductor | DIODE STANDARD 1000V 1A DO204AC |  | 371,590 | In Stock |  | 6 | 6 | Cut Tape (CT) | 4878-1N4007CT-ND | 0.10000 | $0.60 | 1 |  | 4878-1N4007CT-ND | 6 | https://diotec.com/request/datasheet/1n4001.pdf |  | N/A |  | Active | ROHS3 Compliant | 1 (Unlimited) | EAR99 | 8541.10.0080 | China | https://diotec.com/request/imds/p1_e.pdf | 4878-1N4007CT-ND | https://mm.digikey.com/Volume0/opasdata/d220001/derivates/6/003/224/573/4878%7EDO41%28DO204AC%29%7E%7E2_web%28640x640%29.jpg
2 | 0217010.HXP | Littelfuse Inc. | FUSE GLASS 10A 250VAC 5X20MM |  | 20,361 | In Stock |  | 5 | 5 | Bulk | F2398-ND | 0.42000 | $2.10 | 1 |  | F2398-ND | 15 | https://www.littelfuse.com/assetdocs/littelfuse-fuse-217-datasheet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 |  | N/A |  | Active | ROHS3 Compliant | 1 (Unlimited) | EAR99 | 8536.10.0020 | China | https://www.littelfusebusinesscenter.com/LFWeb/rohs_upload/RoHS_Certificate_of_Compliance/CoC_RoHS10_0217010.HXP_02-19-2018.pdf | F2398-ND | https://mm.digikey.com/Volume0/opasdata/d220001/medias/images/2604/METRIC%20FUSES%20217%2C218%20SERIES.jpg
3 | MOV-14D471K | Bourns Inc. | VARISTOR 470V 4.5KA DISC 14MM |  | 3,286 | In Stock |  | 3 | 3 | Bulk | MOV-14D471K-ND | 0.32000 | $0.96 | 1 |  | MOV-14D471K-ND | 13 | https://www.bourns.com/docs/Product-Datasheets/MOV14D.pdf |  | N/A |  | Active | ROHS3 Compliant | Not Applicable | EAR99 | 8533.40.4000 | China | https://www.bourns.com/docs/Product-MDS/MOV-14DxxxK.pdf?sfvrsn=12|https://mm.digikey.com/Volume0/opasdata/d220001/medias/docus/6657/Bourns%20REACH%20247%20Jan%202025%20Statement.pdf|https://www.bourns.com/docs/rohs-cofc/gmov_cofc.pdf?sfvrsn=c25579f6_4 | MOV-14D471K-ND | https://mm.digikey.com/Volume0/opasdata/d220001/medias/images/405/MFG_MOV-14.jpg
4 | P6KE15A | STMicroelectronics | TVS DIODE 12.8VWM 21.2VC DO15 |  | 9,447 | In Stock |  | 4 | 4 | Cut Tape (CT) | 497-14731-1-ND | 0.26000 | $1.04 | 1 |  | 497-14731-1-ND | 25 | https://www.st.com/content/ccc/resource/technical/document/datasheet/1a/3b/f2/a9/96/72/49/ca/CD00000720.pdf/files/CD00000720.pdf/jcr:content/translations/en.C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 |  | N/A |  | Last Time Buy | ROHS3 Compliant | 1 (Unlimited) | EAR99 | 8541.10.0080 | China |  | 497-14731-1-ND | https://mm.digikey.com/Volume0/opasdata/d220001/medias/images/6256/497%7EDO15%7E%7E2.jpg
5 | 212004-01 | Qualtek | CORD 18AWG 5-15P - 320-C13 7.50' |  | 1,053 | In Stock |  | 2 | 2 | Bulk | Q347-ND | 6.21000 | $12.42 | 1 |  | Q347-ND | 26 | https://www.qualtekusa.com/images/Power%20Cords/PDF%20Files/21200401.pdf |  | N/A |  | Active | ROHS3 Compliant | Not Applicable | EAR99 | 8544.42.9090 | Philippines | https://www.qualtekusa.com/wp-content/uploads/2020/04/RoHS_Declaration.pdf|https://www.qualtekusa.com/wp-content/uploads/2020/08/California-Prop-65-Statement.pdf|https://www.qualtekusa.com/wp-content/uploads/2021/04/TSCA-Statement.pdf | Q347-ND | https://mm.digikey.com/Volume0/opasdata/d220001/medias/images/3972/MFG_212013-01.jpg
6 | 723W-BEL3BR51A | Qualtek | C14 INLET W/ FUH, SW, & 0.187 TE |  | 2,624 | In Stock |  | 2 | 2 | Bulk | 189-723W-BEL3BR51A-ND | 4.76000 | $9.52 | 1 |  | 189-723W-BEL3BR51A-ND | 24 | https://qualtekusa.com/wp-content/uploads/specsheets/723w-bel.pdf |  | N/A |  | Active | ROHS3 Compliant | Not Applicable | EAR99 | 8537.10.9170 | Taiwan |  | 189-723W-BEL3BR51A-ND | https://mm.digikey.com/Volume0/opasdata/d220001/derivates/6/003/232/916/MFG_723W-BEL3BR51A_web%28640x640%29.jpg
7 | 221-515 | WAGO Corporation | CARRIER FOR 221 SPLICE HOZ 5P WH |  | 226 | In Stock |  | 10 | 10 | Box | 2946-221-515-ND | 1.40800 | $14.08 | 1 |  | 2946-221-515-ND | 12 | https://wago.priintcloud.com/datasheets/221-515/en/ |  | N/A |  | Active | ROHS3 Compliant | Not Applicable | EAR99 | 3926.90.9989 | China |  | 2946-221-515-ND | https://mm.digikey.com/Volume0/opasdata/d220001/medias/images/4383/MFG_221-505.jpg
8 | 10-03609 | Tensility International Corp | CBL ASSY 2.1MM JACK-CBL RND 1' |  | 4,501 | In Stock |  | 5 | 5 | Bulk | 839-10-03609-ND | 6.40000 | $32.00 | 1 |  | 839-10-03609-ND | 20 | https://tensility.s3.us-west-2.amazonaws.com/uploads/pdffiles/10-03609.pdf |  | N/A |  | Active | ROHS3 Compliant | 1 (Unlimited) | EAR99 | 8544.42.9090 | China |  | 839-10-03609-ND | https://mm.digikey.com/Volume0/opasdata/d220001/medias/images/452/MFG_10-03609.jpg
9 | 10-01936 | Tensility International Corp | CBL ASSY 2.1MM PLG-CBL FLAT 6' |  | 4,242 | In Stock |  | 5 | 5 | Bulk | 839-10-01936-ND | 2.30000 | $11.50 | 1 |  | 839-10-01936-ND | 16 | https://tensility.s3.us-west-2.amazonaws.com/uploads/pdffiles/10-01936.pdf |  | N/A |  | Active | ROHS3 Compliant | 1 (Unlimited) | EAR99 | 8544.42.9090 | China | https://tensility.com/cable-assemblies/10-01936/compliance | 839-10-01936-ND | https://mm.digikey.com/Volume0/opasdata/d220001/medias/images/1241/MFG_10-%5B0177%285%2C6%29%5D%2C%5B0193%285%2C6%29%5D.jpg
10 | 221-503 | WAGO Corporation | CARRIER SCREW MNT 3POS WHITE |  | 1,236 | In Stock |  | 10 | 10 | Box | 2946-221-503-ND | 1.20500 | $12.05 | 1 |  | 2946-221-503-ND | 12 | https://wago.priintcloud.com/datasheets/221-503/en/ |  | N/A |  | Active | ROHS3 Compliant | Not Applicable | EAR99 | 3926.90.9989 | China |  | 2946-221-503-ND | https://mm.digikey.com/Volume0/opasdata/d220001/medias/images/4192/MFG_221-503.jpg
11 | DPE12G7 | Schneider Electric | IEC CONTACTOR, 5HP 480V, 120VAC |  | 460 | In Stock |  | 2 | 2 | Box | 4008-DPE12G7-ND | 35.27000 | $70.54 | 1 |  | 4008-DPE12G7-ND | 3 | https://media.distributordatasolutions.com/228/schneider_synd_json/02c02751ca87d9fd75081f9728bd7238561a8273.pdf |  | N/A |  | Active | ROHS3 Compliant | Not Applicable | EAR99 | 8536.49.0065 | Indonesia |  | 4008-DPE12G7-ND | https://mm.digikey.com/Volume0/opasdata/d220001/medias/images/3648/MFG_DPE09G7.jpg
12 | PC-ABK001F | Bel Inc. | PWR CORD NEMA 5-15P TO C13 1FT |  | 1,176 | In Stock |  | 5 | 5 | Bag | 1847-PC-ABK001F-ND | 2.59000 | $12.95 | 1 |  | 1847-PC-ABK001F-ND | 12 |  |  | N/A |  | Active | ROHS3 Compliant | 1 (Unlimited) | EAR99 | 8544.42.9090 | Vietnam | https://mm.digikey.com/Volume0/opasdata/d220001/medias/docus/6750/24_Cinch%20Connectivity%20Solutions%20PFAS%20Statement.pdf | 1847-PC-ABK001F-ND | https://mm.digikey.com/Volume0/opasdata/d220001/medias/images/4126/MFG_img-STW-PC-ABKXXXU.jpg
13 | 738W-X2/01 | Qualtek | AC RCPT NEMA 5-15R |  | 7,535 | In Stock |  | 5 | 5 | Bag | Q337-ND | 1.15000 | $5.75 | 1 |  | Q337-ND | 18 | https://www.qualtekusa.com/images/AC_Receptacles/pdfs/738wx201.pdf |  | N/A |  | Active | ROHS3 Compliant | Not Applicable | EAR99 | 8536.69.4030 | Taiwan | https://www.qualtekusa.com/wp-content/uploads/2020/04/RoHS_Declaration.pdf|https://www.qualtekusa.com/wp-content/uploads/2020/08/California-Prop-65-Statement.pdf|https://www.qualtekusa.com/wp-content/uploads/2021/04/TSCA-Statement.pdf | Q337-ND | https://mm.digikey.com/Volume0/opasdata/d220001/medias/images/5596/MFG_738W-X2_01_fourth.jpg
14 | 3-350816-2 | TE Connectivity AMP Connectors | CONN QC RCPT 14-16AWG 0.187 |  | 152,278 | In Stock |  | 25 | 25 | Bulk | A27811-ND | 0.22480 | $5.62 | 1 |  | A27811-ND | 6 | https://www.te.com/usa-en/product-3-350816-2.datasheet.pdf |  | N/A |  | Active | ROHS3 Compliant | 1 (Unlimited) | EAR99 | 8536.90.4000 | United States | http://www.te.com/commerce/alt/SinglePartSearch.do?PN=3-350816-2&dest=stmt | A27811-ND | https://mm.digikey.com/Volume0/opasdata/d220001/medias/images/595/3-350816-2.JPG
15 | A22NE-M-P202-N-B | Omron Automation and Safety | SW E-STOP TWIST RESET 10A 120V |  | 37 | In Stock |  | 1 | 1 | Bulk | Z10435-ND | 143.26000 | $143.26 | 1 |  | Z10435-ND | 21 | https://files.omron.eu/downloads/latest/datasheet/en/a263_a22ne_emergency_stop_push_button_switches_datasheet_en.pdf |  | N/A |  | Active | ROHS3 Compliant | Not Applicable | EAR99 | 8536.50.9035 | Japan |  | Z10435-ND | https://mm.digikey.com/Volume0/opasdata/d220001/medias/images/775/A22NE-M-P102-N-B.jpg
16 | ESP32-POE-ISO | Olimex LTD | ESP32-POE IOT EVAL BOARD |  | 513 | In Stock |  | 2 | 2 | Box | 1188-ESP32-POE-ISO-ND | 29.25000 | $58.50 | 1 |  | 1188-ESP32-POE-ISO-ND | 5 | https://mm.digikey.com/Volume0/opasdata/d220001/medias/docus/308/ESP32-POE-ISO_Web.pdf |  | N/A |  | Active | ROHS3 Compliant | 1 (Unlimited) | 5A992C | 8517.62.0090 | Bulgaria | https://www.olimex.com/wiki/GTC#ROHS_.2F_REACH | 1188-ESP32-POE-ISO-ND | https://mm.digikey.com/Volume0/opasdata/d220001/medias/images/310/ESP32-POE-ISO.jpg
17 | 10-02555 | Tensility International Corp | CBL ASSY 2.1MM PLG-PLG FLAT 3' |  | 1,944 | In Stock |  | 5 | 5 | Bulk | 839-10-02555-ND | 3.31000 | $16.55 | 1 |  | 839-10-02555-ND | 16 | https://tensility.s3.us-west-2.amazonaws.com/uploads/pdffiles/10-02555.pdf |  | N/A |  | Active | ROHS3 Compliant | 1 (Unlimited) | EAR99 | 8544.42.9090 | China | https://tensility.com/cable-assemblies/10-02555/compliance | 839-10-02555-ND | https://mm.digikey.com/Volume0/opasdata/d220001/medias/images/2315/MFG_10-02555.jpg
18 | IEC-A-1 | Adam Tech | PWR ENT RCPT IEC320-C14 PANEL QC |  | 3,018 | In Stock |  | 5 | 5 | Tray | 2057-IEC-A-1-ND | 1.03000 | $5.15 | 1 |  | 2057-IEC-A-1-ND | 18 | https://app.adam-tech.com/products/download/data_sheet/203644/iec-a-1-data-sheet.pdf |  | N/A |  | Active | ROHS3 Compliant | 1 (Unlimited) | EAR99 | 8536.69.4030 | China |  | 2057-IEC-A-1-ND | https://mm.digikey.com/Volume0/opasdata/d220001/medias/images/318/IEC-A-1.jpg
19 | 44A0111-16-0-MX | TE Connectivity Raychem Cable Protection | HOOK-UP DL STRND 16AWG BLK FEET |  | 2,157 | In Stock |  | 5 | 5 | DIGI_SPOOL | 44A0111-16-0-MX-DS-ND | 1.29800 | $6.49 | 1 |  | 44A0111-16-0-MX-DS-ND | 12 | https://www.te.com/commerce/DocumentDelivery/DDEController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 |  | N/A |  | Active | ROHS3 Compliant | 1 (Unlimited) | EAR99 | 8544.49.3080 | Mexico | http://www.te.com/commerce/alt/SinglePartSearch.do?PN=282000-015&dest=stmt | 44A0111-16-0-MX-DS-ND | https://mm.digikey.com/Volume0/opasdata/d220001/medias/images/4846/1208_HOOK-UP-STRANDED-BLACK.jpg
20 | 55A0111-16-2 | TE Connectivity Raychem Cable Protection | HOOK-UP STRND16AWG RED FEET |  | 3,117 | In Stock |  | 5 | 5 | DIGI_SPOOL | 484-55A0111-16-2-DS-ND | 1.36200 | $6.81 | 1 |  | 484-55A0111-16-2-DS-ND | 15 | https://www.te.com/commerce/DocumentDelivery/DDEController?Action=srchrtrv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 |  | N/A |  | Active | ROHS3 Compliant | 1 (Unlimited) | EAR99 | 8544.49.3080 | Mexico |  | 484-55A0111-16-2-DS-ND | https://mm.digikey.com/Volume0/opasdata/d220001/medias/images/4849/1208_HOOK-UP-STRANDED-RED.jpg
21 | 24342 | Keystone Electronics | HEX STANDOFF M3 ALUMINUM 25MM |  | 28,342 | In Stock |  | 48 | 48 | Bulk | 36-24342-ND | 0.93000 | $44.64 | 1 |  | 36-24342-ND | 11 | https://www.keyelco.com/userAssets/file/M65p76.pdf |  | N/A |  | Active | ROHS3 Compliant | 1 (Unlimited) | EAR99 | 7616.99.5190 | China | https://www.keyelco.com/userAssets/file/RoHS_Statement.pdf|https://www.keyelco.com/userAssets/file/reach.pdf|https://www.keyelco.com/userAssets/file/Keystone-Prop65%20Declare2022.pdf | 36-24342-ND | https://mm.digikey.com/Volume0/opasdata/d220001/medias/images/561/24342.JPG

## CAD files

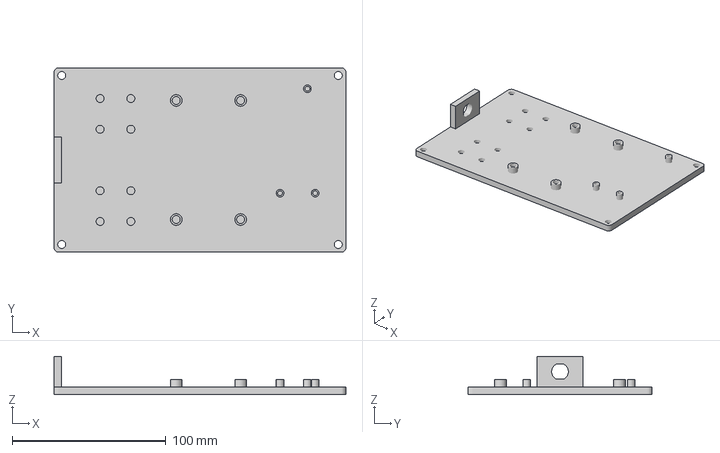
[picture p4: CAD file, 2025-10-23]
hardware/CAD_models/Pump Module - quad relay.3mf
190.0 x 120.0 x 25.0 mm

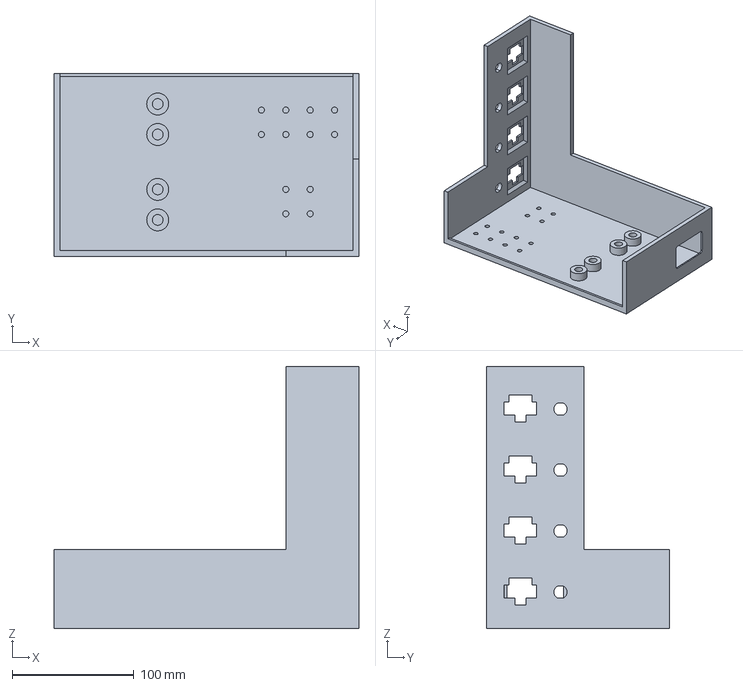
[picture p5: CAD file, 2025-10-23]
hardware/CAD_models/Base Power Tower.3mf
250.0 x 150.0 x 215.0 mm

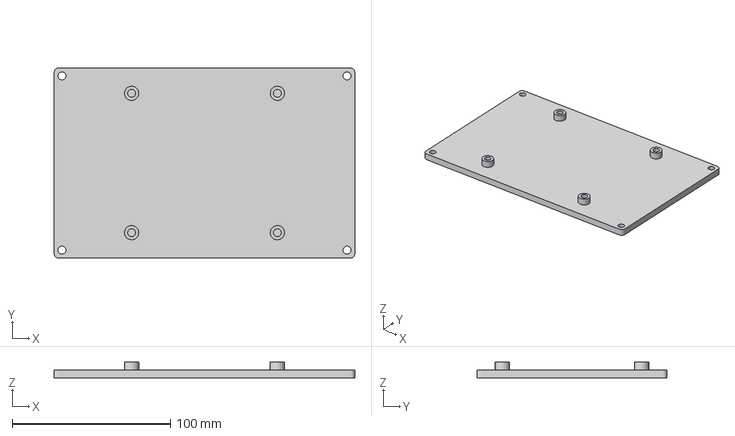
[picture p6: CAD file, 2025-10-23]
hardware/CAD_models/Ultrasonic Driver Module.3mf
190.0 x 120.0 x 10.0 mm

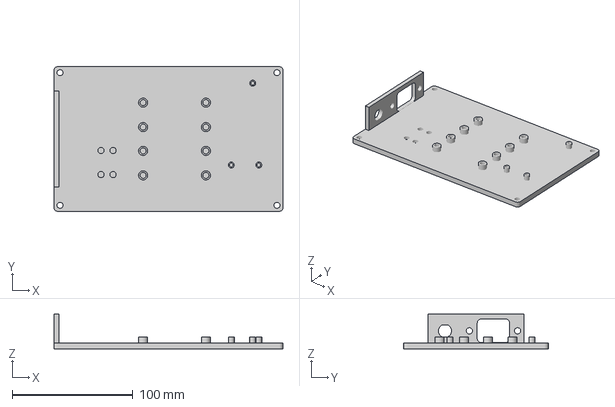
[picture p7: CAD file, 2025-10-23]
hardware/CAD_models/Ultrasonic Module - 2 single relay.3mf
190.0 x 120.0 x 29.0 mm

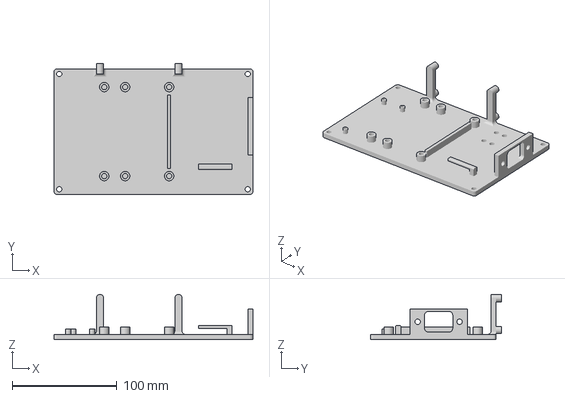
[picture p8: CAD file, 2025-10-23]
hardware/CAD_models/Heater Module - SSR.3mf
190.0 x 125.0 x 43.1 mm

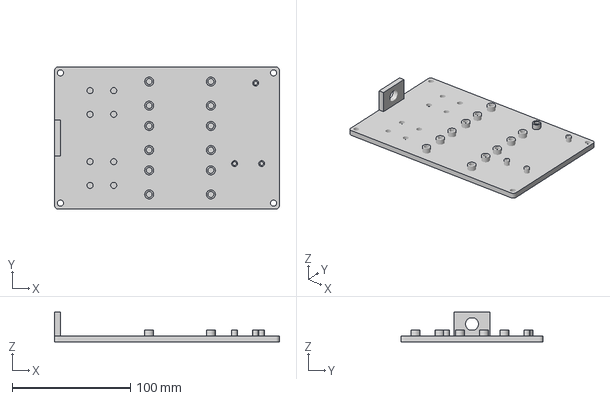
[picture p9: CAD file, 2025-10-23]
hardware/CAD_models/Pump Module - 3 single relay.3mf
190.0 x 120.0 x 25.0 mm

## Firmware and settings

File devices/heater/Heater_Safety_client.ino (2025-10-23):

/*
  ESP32-POE-ISO (Olimex) — Two Heaters via SparkFun Qwiic Dual Solid State Relay
  PID + Thermistor (ADS1015) + MQTT + Safety (controller heartbeat/LWT, MQTT timeout, link-down, max ON lease)

  Commands (MQTT, heat/01/cmd/<1|2>):
    "ON" | "OFF" | "ON:<ms>" | "PWM:<0-100>" | "SET:<tempC>" | "PID:ON" | "PID:OFF"

  MQTT topics:
    heat/01/state/<n>   : retained "ON"/"OFF"
    heat/01/target/<n>  : retained setpoint (float)
    heat/01/temp/<n>    : current temperature (float)
    heat/01/status      : retained "ONLINE"/"OFFLINE"
    heat/01/heartbeat   : "1" every 15s

  Controller supervision (subscribe):
    pyctl/status   : retained "ONLINE"/"OFFLINE" (controller's LWT)
    pyctl/heartbeat: "1" periodically
*/

#include <Wire.h>
#include <WiFi.h>
#include <ETH.h>
#include <WiFiClient.h>
#include <PubSubClient.h>
#include <math.h>

#include "SparkFun_Qwiic_Relay.h"   // Dual SSR (I2C)
#include <SerLCD.h>                 // LCD over Qwiic (I2C)
#include <Adafruit_ADS1X15.h>       // ADS1015/1115
#include <AutoPID.h>                // https://github.com/r-downing/AutoPID

/************ Heater limits ************/
#define HEATER_MAX 100    // PID output upper limit (% slow-PWM)
#define HEATER_MIN 0      // PID output lower limit

/************ Thermistor constants ************/
#define RC     10000.0    // Fixed resistor in divider (ohms)
#define VCC    3.3        // Reference for divider math
#define R25    10000.0    // Thermistor nominal @25°C (ohms)
#define B2585  3977.0     // Beta (25/85°C)

/************ MQTT broker config ************/
const char* MQTT_BROKER_IP = "192.168.0.100";
const uint16_t MQTT_PORT   = 1883;
const char* MQTT_USER      = "heat1";
const char* MQTT_PASS      = "heat";
const char* DEV_BASE       = "heat/01";

/************ Controller supervision ************/
const char* CTRL_STATUS_TOPIC    = "pyctl/status";     // retained ONLINE/OFFLINE (LWT)
const char* CTRL_HEARTBEAT_TOPIC = "pyctl/heartbeat";  // "1" periodically

// Timeouts / leases
const uint32_t CTRL_TIMEOUT_MS   = 25000;  // if no controller beat for this long -> ALL OFF
const uint32_t MQTT_DOWN_OFF_MS  = 20000;  // if reconnect takes longer than this -> ALL OFF
const uint32_t MAX_ON_LEASE_MS   = 60000;  // plain "ON" max lease (0 disables)

/************ Ethernet (Olimex ESP32-POE-ISO) ************/
#define ETH_PHY_TYPE   ETH_PHY_LAN8720
#define ETH_PHY_ADDR   0
#define ETH_PHY_MDC    23
#define ETH_PHY_MDIO   18
#define ETH_POWER_PIN  12
#define ETH_CLK_MODE   ETH_CLOCK_GPIO17_OUT

/************ Relay / device config ************/
#define RELAY_ADDR   0x0A     // Qwiic Dual SSR I2C address
#define HEATER_COUNT 2
#define HEARTBEAT_MS 15000
#define TIMED_SLOTS  4

// ADS1015 thermistor channels
#define TH_CH_1  0           // A0
#define TH_CH_2  3           // A1

/************ Safety (temperature rate brake) ************/
static inline float ema(float prev, float cur, float alpha = 0.05f) {
  if (!isfinite(prev)) return cur;
  return prev + alpha * (cur - prev);
}
const float    DT_MAX_C_PER_S       = 3.0f;     // max allowed dT/dt when heating
const uint32_t IGNORE_AFTER_BOOT_MS = 3000;     // grace period on boot
const float    MIN_DT_FOR_SLOPE_S   = 0.25f;    // ≥250 ms window
const uint32_t PWM_MEMORY_MS        = 3000;     // consider heating if PWM>0 in last 3s
const uint32_t BRAKE_LOG_DEBOUNCE   = 500;      // min ms between brake logs

/************ Globals ************/
WiFiClient   netClient;
PubSubClient mqtt(netClient);
static bool  eth_ready = false;
char clientId[40];

Qwiic_Relay relay(RELAY_ADDR);
bool relay_ok = false;

SerLCD lcd;
Adafruit_ADS1015 ads;

// Cached state (1-based)
bool  heaterIsOn[HEATER_COUNT + 1] = {false};
int   heaterPWM[HEATER_COUNT + 1]  = {0};
// Lease deadlines for plain ON (0 => no lease)
uint32_t leaseUntil[HEATER_COUNT + 1] = {0};

// PID / temps
float  setTarget[HEATER_COUNT + 1]    = {0};
float  tempC[HEATER_COUNT + 1]        = {NAN, NAN, NAN};
bool   pidEnabled[HEATER_COUNT + 1]   = {false};

double pidInput[HEATER_COUNT + 1]     = {0};
double pidOutput[HEATER_COUNT + 1]    = {0};
double pidSetpoint[HEATER_COUNT + 1]  = {0};
double Kp = 4.0, Ki = 0.8, Kd = 0.0;
AutoPID* pid[HEATER_COUNT + 1]        = {nullptr, nullptr, nullptr};

// Timed ON slots
struct Timed {
  uint8_t  ch;
  uint32_t endMs;
  bool     active;
} slots[TIMED_SLOTS];

// Telemetry / timing
uint32_t lastBeat   = 0;
uint32_t lastTelem  = 0;
uint32_t bootMs     = 0;

// For slope safety
float    filtTemp[HEATER_COUNT + 1]     = {NAN, NAN, NAN};
float    lastTempVal[HEATER_COUNT + 1]  = {NAN, NAN, NAN};
uint32_t lastTempMs[HEATER_COUNT + 1]   = {0};
uint32_t lastPwmTime[HEATER_COUNT + 1]  = {0};
uint32_t lastBrakeLog[HEATER_COUNT + 1] = {0};

// Supervision runtime
bool ctrlSeen = false;              // have we seen ONLINE/heartbeat?
unsigned long lastCtrlBeat = 0;     // last controller heartbeat seen
unsigned long lastMqttHealthy = 0;  // last time we were connected/looping OK

/************ Safety: ALL OFF ************/
void allOff(const char* reason) {
  Serial.printf("[SAFETY] ALL OFF (%s)\n", reason ? reason : "unspecified");
  ensureRelay();

  for (uint8_t ch = 1; ch <= HEATER_COUNT; ch++) {
    pidEnabled[ch] = false;
    // force outputs off
    if (relay_ok) {
      relay.setSlowPWM(ch, 0);
      relay.turnRelayOff(ch);
    }
    heaterPWM[ch] = 0;
    heaterIsOn[ch] = false;
    leaseUntil[ch] = 0;

    // publish retained OFF state
    char t[48];
    snprintf(t, sizeof(t), "%s/state/%u", DEV_BASE, ch);
    mqtt.publish(t, "OFF", true);
  }
}

/************ Helpers ************/
bool validCh(uint8_t ch) { return (ch >= 1 && ch <= HEATER_COUNT); }

void write_to_lcd() {
  static uint32_t lastLCD = 0;
  if (millis() - lastLCD < 500) return;
  lastLCD = millis();
  for (int i = 0; i < 2; i++) {
    lcd.setCursor(i * 8, 0);
    lcd.print("C" + String(i+1) + ":" + String(tempC[i+1],1));
    lcd.setCursor(i * 8, 1);
    lcd.print("T:" + String(setTarget[i+1],1));
  }
}

bool ensureRelay() {
  if (!relay_ok) {
    relay_ok = relay.begin();
    if (!relay_ok) {
      Serial.println("[ERROR] Qwiic Dual SSR not detected!");
      return false;
    }
    Serial.println("[I2C] Dual SSR ready.");
  }
  return true;
}

// Read thermistor degC from ADS1015 channel
bool readThermC(uint8_t adsChannel, float &outC) {
  int16_t raw = ads.readADC_SingleEnded(adsChannel);
  float vNode = ads.computeVolts(raw);
  if (vNode < 0.0f) vNode = 0.0f;
  if (vNode > VCC)  vNode = VCC;

  if (fabs(VCC - vNode) < 1e-6) return false;
  double Rntc = RC * (double)vNode / (double)(VCC - vNode);
  if (Rntc <= 0.0) return false;

  double invT = (1.0 / 298.15) + (log(Rntc / R25) / B2585);
  double Tk   = 1.0 / invT;
  outC        = (float)(Tk - 273.15);

  if (!isfinite(outC) || outC < -40.0f || outC > 200.0f) return false;
  return true;
}

/************ Internal setters that DO NOT flip pidEnabled ************/
void _publishState(uint8_t ch) {
  char t[48];
  snprintf(t, sizeof(t), "%s/state/%u", DEV_BASE, ch);
  mqtt.publish(t, heaterIsOn[ch] ? "ON" : "OFF", true);
}

void _setOnOff(uint8_t ch, bool on) {
  if (!ensureRelay()) return;
  if (on) relay.turnRelayOn(ch); else relay.turnRelayOff(ch);
  if (heaterIsOn[ch] != on) {
    heaterIsOn[ch] = on;
    _publishState(ch);
  }
}

void _setPWM(uint8_t ch, int dutyPercent) {
  if (!ensureRelay()) return;
  if (dutyPercent < 0) dutyPercent = 0;
  if (dutyPercent > 100) dutyPercent = 100;
  relay.setSlowPWM(ch, dutyPercent);
  heaterPWM[ch] = dutyPercent;

  bool on = (dutyPercent > 0);
  if (heaterIsOn[ch] != on) {
    heaterIsOn[ch] = on;
    _publishState(ch);
  }
}

/************ Public setters (manual control disables PID) ************/
bool setHeater(uint8_t ch, bool on) {
  if (!validCh(ch)) return false;
  pidEnabled[ch] = false;                 // manual overrides PID
  _setOnOff(ch, on);

  if (on) {
    if (MAX_ON_LEASE_MS > 0) {
      leaseUntil[ch] = millis() + MAX_ON_LEASE_MS;  // start lease
      Serial.printf("[LEASE] Heater %u lease until +%lums\n", ch, (unsigned long)MAX_ON_LEASE_MS);
    }
  } else {
    setTarget[ch] = 0;
    leaseUntil[ch] = 0;                   // clear lease
  }

  Serial.printf("[ACTION] Heater %u -> %s\n", ch, on ? "ON" : "OFF");
  return true;
}

bool setHeaterPWM(uint8_t ch, int dutyPercent) {
  if (!validCh(ch)) return false;
  pidEnabled[ch] = false;                 // manual overrides PID
  _setPWM(ch, dutyPercent);
  Serial.printf("[ACTION] Heater %u PWM -> %d%%\n", ch, dutyPercent);
  return true;
}

bool timedOn(uint8_t ch, uint32_t ms) {
  if (!setHeater(ch, true)) return false;
  for (int i = 0; i < TIMED_SLOTS; i++) {
    if (!slots[i].active) {
      slots[i].active = true;
      slots[i].ch     = ch;
      slots[i].endMs  = millis() + ms;
      Serial.printf("[TIMER] Heater %u OFF in %lu ms\n", ch, ms);
      return true;
    }
  }
  Serial.println("[WARN] No free timer slots");
  return false;
}

bool enablePID(uint8_t ch) {
  if (!validCh(ch)) return false;
  pidEnabled[ch]  = true;
  pidSetpoint[ch] = setTarget[ch];

  // publish target retained
  char t[48], p[16];
  snprintf(t, sizeof(t), "%s/target/%u", DEV_BASE, ch);
  dtostrf(setTarget[ch], 0, 1, p);
  mqtt.publish(t, p, true);

  Serial.printf("[PID] Enabled on heater %u (target=%.1f°C)\n", ch, setTarget[ch]);
  return true;
}

bool disablePID(uint8_t ch) {
  if (!validCh(ch)) return false;
  pidEnabled[ch] = false;
  _setPWM(ch, 0);
  setTarget[ch] = 0;
  Serial.printf("[PID] Disabled on heater %u\n", ch);
  return true;
}

/************ MQTT helpers ************/
void publishStatus(const char* s) {
  char t[48];
  snprintf(t, sizeof(t), "%s/status", DEV_BASE);
  mqtt.publish(t, s, true);
}

void publishTemp(uint8_t ch) {
  char t[48], p[16];
  snprintf(t, sizeof(t), "%s/temp/%u", DEV_BASE, ch);
  dtostrf(tempC[ch], 0, 1, p);
  mqtt.publish(t, p, false);
}

void publishTarget(uint8_t ch) {
  char t[48], p[16];
  snprintf(t, sizeof(t), "%s/target/%u", DEV_BASE, ch);
  dtostrf(setTarget[ch], 0, 1, p);
  mqtt.publish(t, p, true);
}

/************ MQTT connect / supervision subscribe ************/
void ensureMqtt() {
  if (!eth_ready) return;

  while (!mqtt.connected()) {
    uint32_t id = (uint32_t)ESP.getEfuseMac();
    snprintf(clientId, sizeof(clientId), "heat01-%08X", id);

    Serial.printf("[MQTT] Connecting to %s:%d as %s...\n", MQTT_BROKER_IP, MQTT_PORT, clientId);
    if (mqtt.connect(clientId, MQTT_USER, MQTT_PASS,
                     (String(DEV_BASE) + "/status").c_str(), 1, true, "OFFLINE")) {
      Serial.println("[MQTT] Connected");
      lastMqttHealthy = millis();
      publishStatus("ONLINE");

      // Device command subscription
      char filter[48];
      snprintf(filter, sizeof(filter), "%s/cmd/#", DEV_BASE);
      mqtt.subscribe(filter, 0);
      Serial.printf("[MQTT] Subscribed: %s\n", filter);

      // Supervision subscriptions
      mqtt.subscribe(CTRL_STATUS_TOPIC, 1);
      mqtt.subscribe(CTRL_HEARTBEAT_TOPIC, 0);
      Serial.printf("[MQTT] Subscribed: %s, %s\n", CTRL_STATUS_TOPIC, CTRL_HEARTBEAT_TOPIC);

      // don’t trip on boot
      lastCtrlBeat = millis();

      // Republish retained state/target
      for (uint8_t i = 1; i <= HEATER_COUNT; i++) {
        _publishState(i);
        if (pidEnabled[i]) publishTarget(i);
      }
    } else {
      Serial.printf("[MQTT] Failed (rc=%d). Retrying...\n", mqtt.state());
      delay(1200);

      // Hard fail-safe if reconnect taking too long
      if (millis() - lastMqttHealthy > MQTT_DOWN_OFF_MS) {
        allOff("MQTT reconnect timeout");
      }
    }
  }
}

/************ MQTT message handler ************/
void handleCmd(const char* topic, const char* payload) {
  const char* p = strrchr(topic, '/');
  int ch = (p ? atoi(p + 1) : -1);
  if (!validCh(ch)) {
    Serial.printf("[WARN] Invalid topic: %s\n", topic);
    return;
  }
  Serial.printf("[CMD] ch=%d <- %s\n", ch, payload);

  if (strncasecmp(payload, "PWM:", 4) == 0) {
    int duty = atoi(payload + 4);
    setHeaterPWM(ch, duty);
    return;
  }
  if (strncasecmp(payload, "ON:", 3) == 0) {
    uint32_t ms = atoi(payload + 3);
    if (ms) timedOn(ch, ms);
    return;
  }
  if (strncasecmp(payload, "SET:", 4) == 0) {
    float t = atof(payload + 4);
    setTarget[ch]   = t;
    pidSetpoint[ch] = t;
    publishTarget(ch);
    Serial.printf("[SET] target[%d] = %.1f°C\n", ch, t);
    return;
  }
  if (strcasecmp(payload, "PID:ON") == 0)  { enablePID(ch);  return; }
  if (strcasecmp(payload, "PID:OFF") == 0) { disablePID(ch); return; }
  if (strcasecmp(payload, "ON") == 0)      { setHeater(ch, true);  return; }
  if (strcasecmp(payload, "OFF") == 0)     { setHeater(ch, false); return; }
}

void onMqtt(char* topic, byte* payload, unsigned int len) {
  char msg[64];
  len = (len < sizeof(msg)-1) ? len : sizeof(msg)-1;
  memcpy(msg, payload, len); msg[len] = '\0';

  // Supervision topics
  if (strcmp(topic, CTRL_HEARTBEAT_TOPIC) == 0) {
    lastCtrlBeat = millis();
    ctrlSeen = true;
    return;
  }
  if (strcmp(topic, CTRL_STATUS_TOPIC) == 0) {
    if (strcasecmp(msg, "OFFLINE") == 0) {
      allOff("controller LWT OFFLINE");
    } else if (strcasecmp(msg, "ONLINE") == 0) {
      lastCtrlBeat = millis();
      ctrlSeen = true;
    }
    return;
  }

  // Device commands
  if (strncmp(topic, DEV_BASE, strlen(DEV_BASE)) == 0) {
    handleCmd(topic, msg);
  }
}

/************ Ethernet events (fail-safe on link down) ************/
void onNetEvent(WiFiEvent_t event) {
  switch (event) {
    case ARDUINO_EVENT_ETH_START:
      ETH.setHostname("esp32-heat");
      Serial.println("[ETH] Started");
      break;
    case ARDUINO_EVENT_ETH_CONNECTED:
      Serial.println("[ETH] Link up");
      break;
    case ARDUINO_EVENT_ETH_GOT_IP:
      eth_ready = true;
      Serial.print("[ETH] IP: "); Serial.println(ETH.localIP());
      break;
    case ARDUINO_EVENT_ETH_DISCONNECTED:
      Serial.println("[ETH] Link down");
      eth_ready = false;
      allOff("Ethernet link down");
      break;
    case ARDUINO_EVENT_ETH_STOP:
      Serial.println("[ETH] Stopped");
      eth_ready = false;
      allOff("Ethernet stopped");
      break;
    default: break;
  }
}

/************ Setup / Loop ************/
void setup() {
  Serial.begin(115200);
  delay(300);
  Serial.println("\n[BOOT] ESP32-POE-ISO heaters (Dual SSR) + PID + thermistor + safety");

  bootMs = millis();

  Wire.begin();
  Wire.setClock(100000);

  // ADS1015
  if (!ads.begin()) {
    Serial.println("[ERROR] ADS1015 not found!");
  } else {
    Serial.println("[I2C] ADS1015 ready");
  }

  // LCD (optional; ignore if not connected)
  lcd.begin(Wire);
  lcd.setBacklight(255, 255, 255);
  lcd.setContrast(5);
  lcd.disableSplash();
  lcd.clear();
  lcd.print("Booting...");
  Serial.println("[I2C] LCD ready");

  relay_ok = relay.begin();
  if (relay_ok) Serial.println("[I2C] Qwiic Dual SSR ready");
  else          Serial.println("[I2C] Qwiic Dual SSR NOT detected");

  WiFi.onEvent(onNetEvent);
  Serial.println("[ETH] Bringing up Ethernet...");
  ETH.begin(ETH_PHY_TYPE, ETH_PHY_ADDR, ETH_PHY_MDC, ETH_PHY_MDIO, ETH_POWER_PIN, ETH_CLK_MODE);

  // Start OFF + init arrays
  for (uint8_t i = 1; i <= HEATER_COUNT; i++) {
    heaterIsOn[i]   = false;
    heaterPWM[i]    = 0;
    pidEnabled[i]   = false;
    setTarget[i]    = 0;
    tempC[i]        = NAN;
    filtTemp[i]     = NAN;
    lastTempVal[i]  = NAN;
    lastTempMs[i]   = millis();
    leaseUntil[i]   = 0;
    if (relay_ok) {
      relay.setSlowPWM(i, 0);
      relay.turnRelayOff(i);
    }
  }

  // PID controllers
  for (uint8_t i = 1; i <= HEATER_COUNT; i++) {
    pid[i] = new AutoPID(&pidInput[i], &pidSetpoint[i], &pidOutput[i],
                         HEATER_MIN, HEATER_MAX, Kp, Ki, Kd);
    pid[i]->setBangBang(2);     // ±2°C
    pid[i]->setTimeStep(1000);  // 1 s
  }

  mqtt.setServer(MQTT_BROKER_IP, MQTT_PORT);
  mqtt.setCallback(onMqtt);
  mqtt.setKeepAlive(30);

  // Seed timers so we don't trip immediately
  lastCtrlBeat    = millis();
  lastMqttHealthy = millis();
  ctrlSeen        = false;

  Serial.println("[BOOT] Setup complete.\n");
  lcd.clear();
}

void loop() {
  uint32_t now = millis();

  write_to_lcd();

  // Maintain MQTT, record last healthy time
  if (eth_ready && !mqtt.connected()) ensureMqtt();
  if (mqtt.connected()) {
    mqtt.loop();
    lastMqttHealthy = now;
  }

  // Refresh 'now' AFTER mqtt.loop() so comparisons use a time >= lastCtrlBeat
  now = millis();

  // Controller heartbeat timeout -> OFF (use signed delta to avoid underflow)
  if (mqtt.connected() && ctrlSeen) {
    int32_t dt = (int32_t)(now - lastCtrlBeat);  // signed
    if (dt >= 0 && (uint32_t)dt > CTRL_TIMEOUT_MS) {
      static uint32_t lastTimeoutLog = 0;
      if (now - lastTimeoutLog > 2000) {
        Serial.printf("[SAFETY] CTRL timeout: delta=%ldms (> %lums)\n",
                      (long)dt, (unsigned long)CTRL_TIMEOUT_MS);
        lastTimeoutLog = now;
      }
      allOff("controller heartbeat timeout");
      // Do NOT fake the beat by writing lastCtrlBeat=now; just wait for a real heartbeat.
      ctrlSeen = false;  // require a fresh ONLINE/heartbeat before enforcing again
    }
  }

  // --- Thermistors (read + filter) ---
  float t1, t2;
  bool ok1 = readThermC(TH_CH_1, t1);
  bool ok2 = readThermC(TH_CH_2, t2);
  tempC[1] = ok1 ? t1 : NAN;
  tempC[2] = ok2 ? t2 : NAN;

  for (uint8_t ch = 1; ch <= HEATER_COUNT; ch++) {
    if (isfinite(tempC[ch])) {
      filtTemp[ch] = ema(filtTemp[ch], tempC[ch]);
    }
  }

  // --- PID control if enabled ---
  for (uint8_t ch = 1; ch <= HEATER_COUNT; ch++) {
    if (pidEnabled[ch]) {
      if (isfinite(filtTemp[ch])) {
        pidInput[ch]   = filtTemp[ch];
        pidSetpoint[ch]= setTarget[ch];
        pid[ch]->run();                      // updates pidOutput[ch]
        _setPWM(ch, (int)pidOutput[ch]);    // internal setter
        if (heaterPWM[ch] > 0) lastPwmTime[ch] = now;
      } else {
        _setPWM(ch, 0);                      // sensor bad -> off
      }
    }
  }

  // --- Safety: rate-of-rise brake ---
  for (uint8_t ch = 1; ch <= HEATER_COUNT; ch++) {
    if (!isfinite(filtTemp[ch])) continue;
    if (now - bootMs < IGNORE_AFTER_BOOT_MS) continue;

    float dt_s = (now - lastTempMs[ch]) / 1000.0f;
    if (dt_s < MIN_DT_FOR_SLOPE_S) continue;

    bool activelyHeating = pidEnabled[ch] || (now - lastPwmTime[ch] < PWM_MEMORY_MS);
    if (!activelyHeating) {
      lastTempVal[ch] = filtTemp[ch];
      lastTempMs[ch]  = now;
      continue;
    }

    if (isfinite(lastTempVal[ch])) {
      float dT = (filtTemp[ch] - lastTempVal[ch]) / dt_s;
      if (dT > DT_MAX_C_PER_S) {
        _setPWM(ch, 0);
        _setOnOff(ch, false);

        if (now - lastBrakeLog[ch] > BRAKE_LOG_DEBOUNCE) {
          lastBrakeLog[ch] = now;
          Serial.printf("[SAFETY] CH%u dT/dt=%.2f C/s too high -> brake\n", ch, dT);
        }
      }
    }
    lastTempVal[ch] = filtTemp[ch];
    lastTempMs[ch]  = now;
  }

  // --- Heartbeat + telemetry ---
  if (mqtt.connected()) {
    if (now - lastBeat > HEARTBEAT_MS) {
      lastBeat = now;
      String tb = String(DEV_BASE) + "/heartbeat";
      mqtt.publish(tb.c_str(), "1");
      Serial.println("[HEARTBEAT] Sent");
    }
    if (now - lastTelem > 3000) {
      lastTelem = now;
      for (uint8_t ch = 1; ch <= HEATER_COUNT; ch++) {
        if (isfinite(filtTemp[ch])) publishTemp(ch);
        if (pidEnabled[ch])        publishTarget(ch);
      }
    }
  }

  // Timed OFF handling
  for (int i = 0; i < TIMED_SLOTS; i++) {
    if (slots[i].active && now >= slots[i].endMs) {
      setHeater(slots[i].ch, false);
      slots[i].active = false;
      Serial.printf("[TIMER] Heater %u OFF (expired)\n", slots[i].ch);
    }
  }

  // Lease OFF handling for plain ON
  if (MAX_ON_LEASE_MS > 0) {
    for (uint8_t ch = 1; ch <= HEATER_COUNT; ch++) {
      if (leaseUntil[ch] && now >= leaseUntil[ch]) {
        Serial.printf("[LEASE] Heater %u lease expired -> OFF\n", ch);
        setHeater(ch, false);
        leaseUntil[ch] = 0;
      }
    }
  }

  delay(20);
}

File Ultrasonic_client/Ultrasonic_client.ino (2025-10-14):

/*
  This example code gives you all the functionality of the SparkFun Qwiic Relay
  Arduino Library. It shows you how to get the firmware version of the board
  you're using, how to turn on and off a relay, toggle a relay, and get the
  status of the relay.
  By: Elias Santistevan
  SparkFun Electronics
  Date: July 2019

  License: This code is public domain but you buy me a beer if you use 
	this and we meet someday (Beerware license).
*/

#include <Wire.h>
#include <ETH.h>
#include <PubSubClient.h>
#include <WiFi.h>
#include <WiFiClient.h>
#include "SparkFun_Qwiic_Relay.h"

/************ MQTT broker config ************/
const char* MQTT_BROKER_IP   = "192.168.0.102";   // your laptop/broker IP
const uint16_t MQTT_PORT     = 1883;
const char* MQTT_USER        = "ultra1";
const char* MQTT_PASS        = "ultra";
const char* DEV_BASE         = "ultra/01";

/************ Ethernet (Olimex ESP32-POE-ISO) ************/
#define ETH_PHY_TYPE   ETH_PHY_LAN8720
#define ETH_PHY_ADDR   0
#define ETH_PHY_MDC    23
#define ETH_PHY_MDIO   18
#define ETH_POWER_PIN  12
#define ETH_CLK_MODE   ETH_CLOCK_GPIO17_OUT

/************ Relay config ************/
#define RELAY_ADDR_1     0x0A
#define ULTRA_COUNT      2          // exactly two ultrasonic outputs: 1..2
#define HEARTBEAT_MS     15000
#define TIMED_SLOTS      4

/************ Globals ************/
WiFiClient   netClient;
PubSubClient mqtt(netClient);
static bool eth_ready = false;
char clientId[40];

Qwiic_Relay relay(RELAY_ADDR_1); 
bool relay_ok = false;       // whether .begin() succeeded
bool ultraIsOn[ULTRA_COUNT + 1] = {false}; // 1-based cache for retained publishes

// Represents a scheduled auto-OFF task triggered by "ON:<ms>"
struct TimeRun {
  uint8_t ch; 
  uint32_t endMs; 
  bool active; 
} slots[TIMED_SLOTS];

unsigned long lastBeat = 0; // Timestamp of the last heartbeat publish

/************ Helpers ************/

// Convert a user-facing ultrasonic channel number to a relay instance & channel 
bool chanToRelay(uint8_t ch, Qwiic_Relay*& board, uint8_t& relayCh) {
  if (ch < 1 || ch > ULTRA_COUNT) return false; 
  board = &relay; 
  relayCh = ch;   // 1->relay#1, 2->relay#2
  return true;
}

// Force an ultrasonic channel ON or OFF and publish retained state
bool setUltra(uint8_t ch, bool on) {
  Qwiic_Relay* b = nullptr; uint8_t rch = 0;
  if (!chanToRelay(ch, b, rch)) {
    Serial.printf("[WARN] Invalid ultrasonic channel: %d\n", ch);
    return false;
  }

  if (!relay_ok) {
    Serial.println("[INFO] Relay not initialized, trying begin()...");
    relay_ok = b->begin();
    if (!relay_ok) {
      Serial.println("[ERROR] Qwiic Relay not detected on I2C!");
      return false;
    }
  }

  Serial.printf("[ACTION] Ultrasonic %d -> %s\n", ch, on ? "ON" : "OFF");
  if (on) b->turnRelayOn(rch);
  else    b->turnRelayOff(rch);

  ultraIsOn[ch] = on;

  char topic[48];
  snprintf(topic, sizeof(topic), "%s/state/%u", DEV_BASE, ch);
  mqtt.publish(topic, on ? "ON" : "OFF", true); // retained
  return true;
}

// Read the current hardware state of an ultrasonic channel from the relay
bool getUltraStateFromHW(uint8_t ch, bool& on) {
  Qwiic_Relay* b = nullptr; uint8_t rch = 0;
  if (!chanToRelay(ch, b, rch)) return false;

  if (!relay_ok) relay_ok = b->begin();
  if (!relay_ok) return false;

  uint8_t s = b->getState(rch);  // 0 = off, 1 = on
  on = (s == 1);
  Serial.printf("[STATE] Ultrasonic %d current state: %s\n", ch, on ? "ON" : "OFF");
  return true;
}

/************ MQTT ************/

// Publish device status to "<DEV_BASE>/status" as a retained message.
void publishStatus(const char* s) {
  char topic[48]; 
  snprintf(topic, sizeof(topic), "%s/status", DEV_BASE);
  mqtt.publish(topic, s, true);
  Serial.printf("[MQTT] Status published: %s\n", s); 
}

// Ensure MQTT is connected; if not, (re)connect and subscribe to command topics.
void ensureMqtt() {
  if (!eth_ready) return; 

  while (!mqtt.connected()) {
    uint32_t id = (uint32_t)ESP.getEfuseMac(); 
    snprintf(clientId, sizeof(clientId), "ultra01-%08X", id); 

    Serial.printf("[MQTT] Connecting to %s:%d as %s...\n", MQTT_BROKER_IP, MQTT_PORT, clientId);
    if (mqtt.connect(clientId, MQTT_USER, MQTT_PASS,
                     (String(DEV_BASE) + "/status").c_str(), 1, true, "OFFLINE")) {
      Serial.println("[MQTT] Connected successfully!");
      publishStatus("ONLINE");

      // Subscribe to commands: ultra/01/cmd/<n>
      char filter[48];
      snprintf(filter, sizeof(filter), "%s/cmd/#", DEV_BASE);
      mqtt.subscribe(filter, 0);
      Serial.printf("[MQTT] Subscribed to: %s\n", filter);

      // Republish current states (retained)
      for (uint8_t i = 1; i <= ULTRA_COUNT; i++) {
        bool on = false;
        if (getUltraStateFromHW(i, on)) {
          char t[48];
          snprintf(t, sizeof(t), "%s/state/%u", DEV_BASE, i);
          mqtt.publish(t, on ? "ON" : "OFF", true);
        }
      }
    } else {
      Serial.printf("[MQTT] Failed (rc=%d). Retrying...\n", mqtt.state());
      delay(1500);
    }
  }
}

// Handle an incoming command message for a specific channel.
void handleCmd(const char* topic, const char* payload) {
  // topic: ultra/01/cmd/<n>
  // payload: "ON" | "OFF" | "ON:<ms>"
  int ch = -1; 
  const char* p = strrchr(topic, '/');
  if (p) ch = atoi(p + 1); 
  if (ch < 1 || ch > ULTRA_COUNT) {
    Serial.printf("[WARN] Invalid topic: %s\n", topic);
    return; 
  }

  Serial.printf("[MQTT] Command received: ultra %d <- %s\n", ch, payload);

  if (strncasecmp(payload, "ON:", 3) == 0) {
    uint32_t ms = atoi(payload + 3);
    if (ms == 0) return;
    if (!setUltra(ch, true)) return;

    for (int i = 0; i < TIMED_SLOTS; i++) {
      if (!slots[i].active) {
        slots[i].active = true;
        slots[i].ch     = ch;
        slots[i].endMs  = millis() + ms;
        Serial.printf("[TIMER] Ultra %d scheduled OFF in %lu ms\n", ch, ms);
        break;
      }
    }
    return;
  }

  if (strcasecmp(payload, "ON") == 0) setUltra(ch, true);
  else if (strcasecmp(payload, "OFF") == 0) setUltra(ch, false);
}

// PubSubClient callback adapter: converts raw payload to C-string and dispatches to handleCmd().
void onMqtt(char* topic, byte* payload, unsigned int len) {
  char msg[40];
  len = (len < sizeof(msg)-1) ? len : sizeof(msg)-1;
  memcpy(msg, payload, len); msg[len] = '\0';
  handleCmd(topic, msg);
}
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

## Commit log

2025-10-16 Update BOM
2025-10-23 Big update to the repo structure with detailed README
    also added safety supervision code
    [Base Power Tower.3mf, Heater Module - SSR.3mf, Modular MQTT Tower.xlsx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]
